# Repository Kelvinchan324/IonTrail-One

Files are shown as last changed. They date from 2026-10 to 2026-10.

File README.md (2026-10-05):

## EVT-A build and teaching manual (5 October 2026)

The runnable draft is a **USB-powered ESP32-C3 counter with a guarded SEN0463,
SHT40 and SSD1306 display**. Its 170 x 100 mm bench fixture is a development step;
the pocket battery product below remains a future design.

[Engineering manual](docs/engineering.md) · [BOM](hardware/BOM.md) ·
[Wiring schematic](hardware/schematic.svg) · [Placement drawing](mechanical/placement.svg) ·
[STEP draft](mechanical/layout-draft.step)

1. Confirm the exact C3 board, OLED pin order and 3.3 V signal levels against the
   engineering manual. Keep the detector guard closed. Do the first test with
   the detector disconnected and injected low-voltage pulses only.
2. Install PlatformIO, then run `pio run`, `pio run --target upload`, and
   `pio device monitor` at 115200 baud.
3. The screen starts at WAIT and reports CPM after ten seconds. A missing screen
   or environmental sensor should not prevent serial counting.
4. Supply 10 Hz pulses from a separate 3.3 V fixture through 1k into GPIO3.
   Collect at least three full windows and run
   `python tools/check_log.py capture.csv --hz 10`. Expect about 600 CPM.
5. Power off, remove the fixture, then connect the detector's low-voltage output.
   Record natural background counts. Hold the count-reset button for two seconds
   to clear totals; the next full measurement again takes ten seconds.
6. Complete the five lessons in the engineering manual before changing hardware.

The software emits CSV count/environment readings. It does not measure calibrated
dose, certify a safe environment or prove sensor health when counts are zero.
The CAD is a guarded-module packaging draft. Battery, custom HV board and final
pocket enclosure work are not complete.

New review drafts: [secondary bench cover STEP/STL and fit lesson](mechanical/README.md)
and [low-voltage power-budget worksheet](docs/power-review.md). Reproduce the
planning arithmetic with `python tools/check_power_budget.py`. Current allowances,
guard dimensions, retention and temperature remain unmeasured; passing the script
is not hardware approval.

The [STEP-derived enclosure review](mechanical/enclosure-visual-review.png) now
labels component positions and shows the lid raised for inspection only. The
detector guard size is still assumed, modules are not positively retained, and
the reset button cannot be used through the closed draft lid. These are open
design requirements; the illustration is not a fabrication or electrical release.

### Verification and troubleshooting

- Run `python -m pytest tests`; production counting-library host tests are
  documented in [tests/README.md](tests/README.md).
- Log validation checks raw window counts, elapsed time, total-count continuity
  and frequency agreement, not just the displayed CPM.
- WAIT: no full post-start/reset window yet. FAULT or `counts_valid=0`: counter
  overflow; stop the test, investigate, reset and record a new capture.
- `sensor_ok=0`: environmental data unavailable; it says nothing about GM health.
- Missing climate sensor at boot: initialization is retried once per completed
  count window. Failed or invalid reads publish `nan,nan,0`; the display stops
  showing a climate sample after 15 seconds without a valid update. Recovery
  requires a successful new read, not merely an I2C address acknowledgement.
- INIT FAIL: counter initialization failed; no count rows are emitted. A blinking
  status LED indicates loop activity only, not sensor or counter health.
- The SDK rejects out-of-range GPIO numbers and interrupt modes other than
  FALLING/RISING before touching the current acquisition. A successful `begin`
  still does not verify interrupt attachment or detector health. See the
  [counter-configuration lesson](docs/counter-configuration.md).
- OLED missing or initialization failed at boot: serial counting can continue,
  with a display connection probe/retry every two seconds. Detected loss suspends
  drawing; recovery reinitializes the display without restarting the shared bus.
  `# oled` log comments report transitions, not proof of working pixels. See the
  [display-recovery lesson](docs/display-recovery.md). Power off before checking
  wiring; do not hot-plug the detector or use this as permission to live-rewire.
- Zero counts cannot distinguish quiet conditions from a broken detector path.
- Record actual results in the [bench worksheet](docs/bench-record.md).

See the [environmental-data validity lesson](docs/climate-validity.md). The log
checker now checks climate fields when present; its pass result still certifies
neither sensor accuracy nor radiation dose.

The [application-loop lesson](docs/application-testing.md) now exercises the
production setup/loop and counter using host-only sensor/display doubles.
It covers missing/failed climate reads, delayed I/O, reset timing and counter
startup failure. This is simulated behavior coverage, not a physical bus test or
OLED pixel/layout validation; the lesson includes a separate pending bench record.

<p align="center">
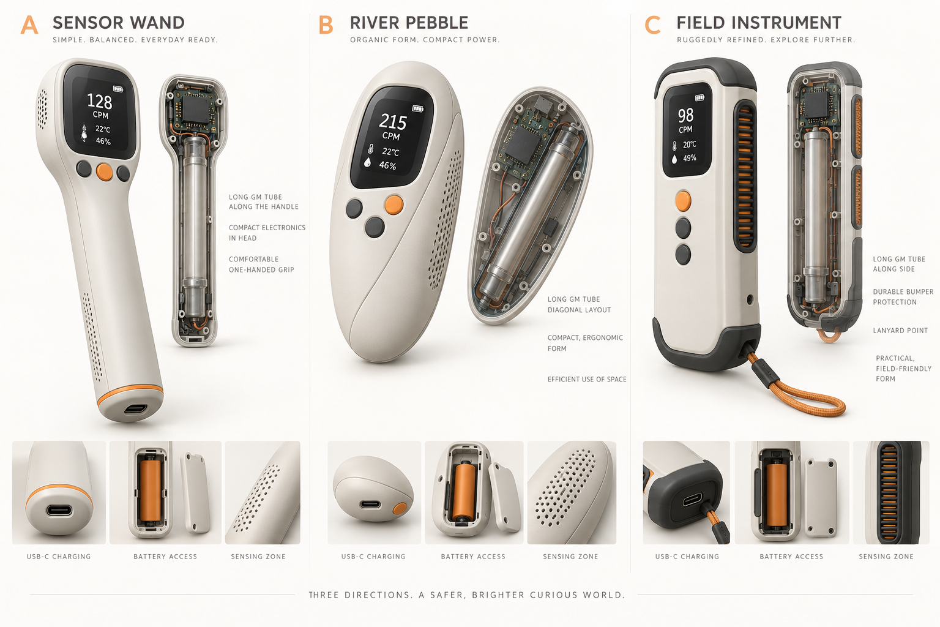
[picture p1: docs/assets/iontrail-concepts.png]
IonTrail One enclosure study
  
</p>

<p align="center">
  <strong>IonTrail One</strong><br>
  A pocketable environmental radiation counter designed to be explored, extended, and made your own.
</p>

<p align="center">
  <a href="docs/index.html"><strong>Product-page source</strong></a> ·
  <a href="docs/quickstart.md">SDK quick start</a> ·
  <a href="docs/hardware.md">Hardware architecture</a> ·
  <a href="docs/customization.md">Customization guide</a>
</p>

<p align="center">
  
  
  
</p>

---

## See the invisible environment

IonTrail One is a planned consumer environmental instrument built around a Geiger–Müller tube, an ESP32-C3, and temperature/humidity sensing. Its river-pebble enclosure uses a smoked transparent back to reveal the tube and custom PCB, while a structural loop lets it travel on a bag or lanyard.

The product is designed for home science, STEM learning, makers, collectors, and people curious about the world around them. CPM/CPS is the primary radiation measurement; environmental readings provide context for experiments and logged observations.

> **Development status:** concept and EVT planning. Dimensions, battery life, radiation response, dose conversion, ingress protection, and accuracy are not final specifications until verified on production-representative hardware.

## Product principles

| Principle | What it means |
| --- | --- |
| Understandable | The main screen explains the current count rate without presenting an unverified “safe/unsafe” judgement. |
| Customizable | The public SDK exposes count events, CPM, environmental readings, alarms, logging, and display hooks. |
| Repairable | A screwed enclosure, replaceable subassemblies, test points, and versioned hardware documentation are preferred. |
| Honest | Dose-rate estimates remain optional and require tube-specific calibration data supplied by the user or manufacturer. |
| Safe by design | The high-voltage section is physically guarded, current-limited, and inaccessible despite the transparent back. |

## Planned hardware

```mermaid
flowchart LR
    USB[USB-C 5 V] --> CHG[Protected charger<br/>and power path]
    CELL[Protected 1-cell LiPo<br/>with NTC] --> CHG
    CHG --> REG[3.3 V regulation]
    REG --> MCU[ESP32-C3]
    REG --> DISP[OLED display]
    REG --> ENV[SHT40 temperature/RH]
    REG --> HV[Regulated GM high voltage]
    HV --> TUBE[GM tube]
    TUBE --> PULSE[Pulse conditioning<br/>and input protection]
    PULSE --> MCU
    MCU --> FEEDBACK[Buzzer + pulse LED]
    MCU --> BLE[BLE customization API]
```

The ESP32-C3 SuperMini is used for fast EVT prototypes. A sellable revision should use a certified ESP32-C3 module on a custom PCB with traceable power components, protected battery charging, controlled high voltage, and production test points.

Read the full [hardware architecture](docs/hardware.md) and [prototype BOM](docs/bom.md).

## SDK overview

The SDK is organized as a small Arduino/PlatformIO library. Applications can subscribe to count-rate data, change display behavior, implement their own alarms, add BLE services, or connect additional I2C sensors without rewriting the pulse-counting core.

```cpp
#include <IonTrail.h>

IonTrailDevice ionTrail;
bool counterReady = false;

void setup() {
  Serial.begin(115200);
  IonTrailConfig config;
  config.gmPulsePin = 3;
  config.sampleWindowMs = 10000;
  config.deadTimeMicros = 0; // Enable only with characterized tube data.
  counterReady = ionTrail.begin(config);
  if (!counterReady) Serial.println("# counter INIT FAIL; no measurements");
}

void loop() {
  if (!counterReady) return;
  ionTrail.update();

  if (ionTrail.hasFreshReading()) {
    Serial.printf("CPM: %.1f  Total: %lu\n",
                  ionTrail.cpm(),
                  static_cast<unsigned long>(ionTrail.totalCounts()));
  }
}
```

### What customers can customize

- Screen layouts, icons, units, languages, and themes
- Count-click sound, LED behavior, and alarm thresholds
- BLE characteristics and companion applications
- CSV/JSON logging and cloud integrations
- Environmental sensors on the shared I2C expansion bus
- Experiment modes and classroom activities
- Tube-specific calibration profiles
- Power-saving and sampling strategies

The initial library deliberately does **not** make a universal CPM-to-µSv/h conversion. See [calibration and claims](docs/safety.md).

## Start developing

1. Install [Visual Studio Code](https://code.visualstudio.com/) and [PlatformIO](https://platformio.org/).
2. Clone this repository.
3. Connect an ESP32-C3 SuperMini by USB.
4. Review and confirm the pins in `include/iontrail_board.h` against your exact board revision.
5. Build and upload the default environment:

```bash
pio run
pio run --target upload
pio device monitor
```

See the [quick-start guide](docs/quickstart.md) before connecting any GM high-voltage hardware.

## Repository map

```text
IonTrail-One/
├── include/                 Board-level pin configuration
├── lib/IonTrail/            Reusable SDK library
├── src/                     Reference firmware application
├── examples/                Customer customization examples
├── docs/                    Product, hardware and SDK documentation
├── platformio.ini           Reproducible ESP32-C3 build
├── CONTRIBUTING.md          Contribution workflow
└── LICENSE                  MIT SDK licence
```

The static product site is ready in `docs/`. To publish it at `kelvinchan324.github.io/IonTrail-One`, enable **Settings → Pages → Build and deployment → GitHub Actions** once; the included workflow handles later deployments.

## Safety boundary

IonTrail One is an educational and environmental-monitoring project. It is not a certified personal dosimeter, contamination survey meter, medical device, or proof that an environment is safe. A GM circuit can contain several hundred volts even when powered by a small battery. Use a current-limited design, discharge path, insulating guard, and appropriate test equipment. Never connect a tube or high-voltage node directly to an ESP32 pin.

Read [Safety, calibration and product claims](docs/safety.md) before modifying detector hardware or publishing measurements.

## Contributing

Issues, documentation improvements, display themes, sensor integrations, translations, and tested hardware profiles are welcome. Keep safety-critical changes explicit and include test evidence where practical. See [CONTRIBUTING.md](CONTRIBUTING.md).

## Licence

The SDK and repository content are available under the [MIT License](LICENSE). Product names and logos are not granted for use as trademarks. Third-party libraries and hardware modules retain their own licences and terms.

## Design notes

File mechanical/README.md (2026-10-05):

# Secondary bench cover — editable draft, not an electrical guard

Retain the **complete factory SEN0463 enclosure**. This outer cover does not
replace it or certify protection against electric shock, dust, moisture, fire,
drops or access through openings. No pocket or wearable use is approved.

Files:

- [Parameters](enclosure-parameters.json) and [computed checks](enclosure-checks.json).
- [Tray STEP](bench-tray-draft.step) / [STL](bench-tray-draft.stl).
- [Lid STEP](bench-lid-draft.step) / [STL](bench-lid-draft.stl).
- [Assembly with original fixture and component envelopes](enclosure-layout.step).

Generate using `python tools/build_enclosure.py` with CadQuery 2.8.0 after
`python tools/build_engineering.py --cad`. The part generator verifies connected
positive solids, no reference-envelope or fixture-plate intrusion and STEP
roundtrips. It does not model screws, cables, plug insertion or material strength.

## Geometry and fastening

Original fixture datum is unchanged: plate bottom Z=0, top Z=4 mm. Tray bottom
extends to Z=-9; the underside datum is now -9, not the old fixture datum.
Through-bolt heads/nuts may project below it: insulating feet or clearance
supports are still required and not modeled. Do not rest the assembly on fasteners.
The lid footprint is 202 x 107 mm and overall height is 53.5 mm. Four 6 mm-high
support bosses line up with the existing plate holes at X=±78, Y=±43 mm.
Do not confuse these holes with detector or module mounting patterns.

Lid bolts use external ears at X=±95, Y=±43 mm, keeping hardware outside the
detector bay. Holes are 3.4 mm; M3x16 through-bolts are candidates only. Check
washer/nut/tool access and thread engagement on the actual manufactured parts.
The lid is a flat transparent-material candidate, not a proven clear 3D print.
There is no gasket or light-seal performance claim.

The left-wall USB opening is provisional: verify the board connector orientation,
plug size and cable bend before fabrication. Three lid vents are above the
environment sensor, not over the detector. Their existence is not a touch-probe
assessment. The reset button cannot be operated with this lid closed; its
extension actuator remains unresolved. Power must be removed before lid removal.

## Guard retention is deliberately not guessed

The [vendor specification](https://wiki.dfrobot.com/sen0463/) lists a 107 x 42 mm
board. The retained 115 x 48 x 28 mm envelope is an **assumed guard allowance**,
not a measured outer case. No new holes, clamp pressure or fastener force on the
factory guard/tube is specified. Modules are not secured merely by enclosing them.
Do not power, transport or shake this draft until proper retention is reviewed.

## Measurement and CAD lesson

1. With all supplies removed, measure the intact exterior without disassembly.
2. Record guard dimensions, allowed factory mounting points, low-voltage cable
   exit and clearance. Photograph external evidence; never expose the HV section.
3. Update the envelope and regenerate both layout and cover. Investigate any
   intrusion error rather than suppressing it.
4. Design a removable adapter using verified factory mounting features. Do not
   assume adhesive or pressure against a tube is acceptable retention.
5. Prototype fit with inert dummy blocks first. Record wire pinch, plug access,
   lid bow and fastener stack before considering electronics.

| Required measurement | Evidence |
| --- | --- |
| Factory guard W/D/H and allowed retention interfaces | pending |
| Board/connector positions and cable clearance | pending |
| Plate bolt stack and lid-ear nut/tool clearance | pending |
| Insulating feet / underside fastener clearance and stability | pending |
| Transparent lid readability and button solution | pending |
| Material, thickness tolerance, deflection and thermal suitability | pending |
| Positive retention, strain relief and accessible-opening review | pending |

Release remains blocked on these measurements and the
[power/thermal review](../docs/power-review.md). No physical tests have run.

## Visual handoff and source freshness

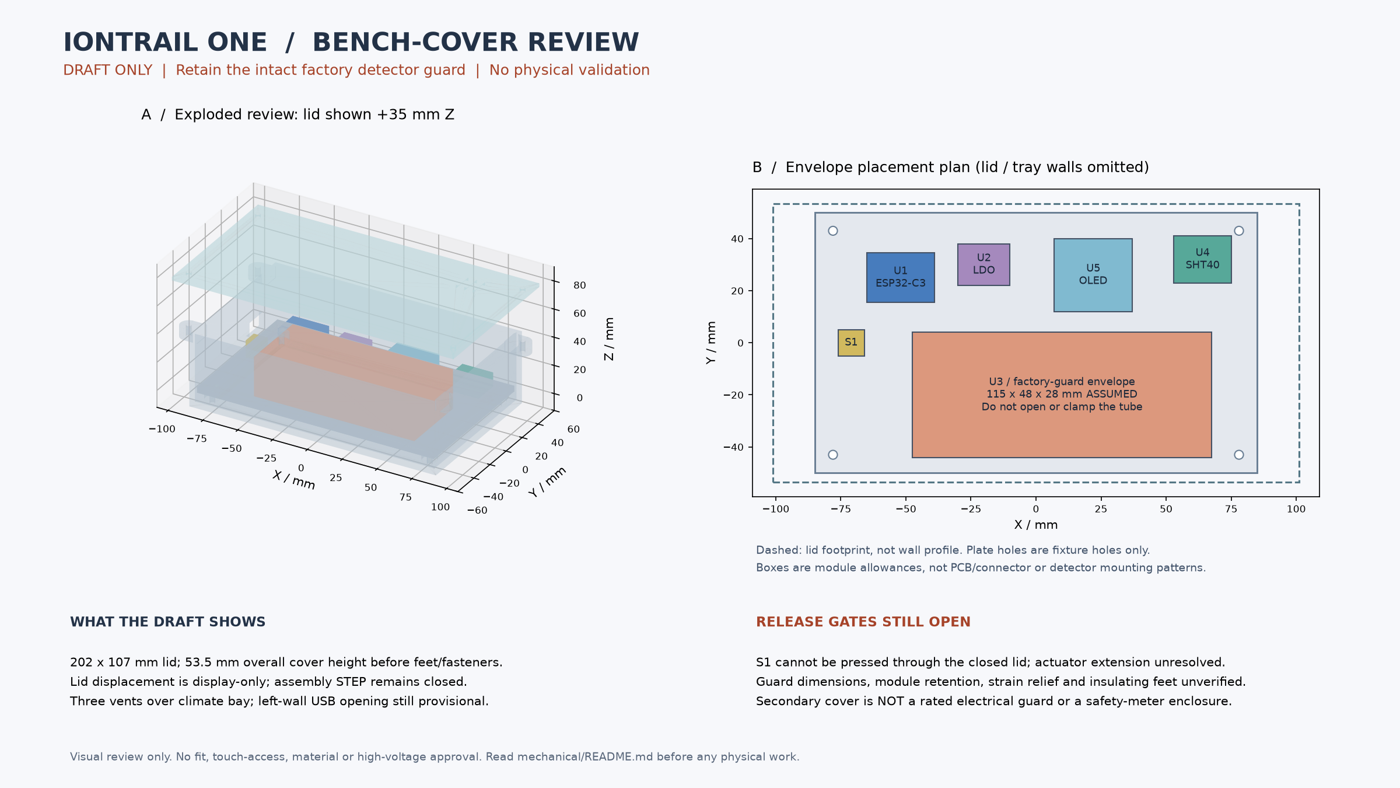
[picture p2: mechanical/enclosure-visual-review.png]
STEP-derived exploded cover and component placement


The left view uses the saved tray, lid and fixture STEP solids with the six
component-envelope boxes. The lid is displaced **35 mm upward for illustration
only**; the original assembly file remains closed. Translucency is an inspection
aid, not a verified material property. The right view omits lid and tray walls to
show component positions: dashed outline is the lid extent, not a wall profile.
Fixture holes are not module mounting patterns. No power wiring is depicted.

The render was visually checked, including correction of an overlapping axis
caption. The plan makes the current division between the guarded detector and
low-voltage electronics clear. It does not establish an electrical isolation
distance or prevent a loose module crossing that division. S1's inaccessible
closed-lid position, missing module retention and underside feet remain release
blockers, not details to overlook during assembly.

Reproduce with CadQuery 2.8.0 and Matplotlib 3.11.2:

```sh
python tools/render_enclosure_review.py
python -m pytest tests/test_visual_review.py
```

The [ledger](enclosure-visual-review.json) records input/image hashes, versions
and nine matched bodies. Before drawing, the renderer checks one-to-one body
volumes (within 1e-4 mm3) and bounds (within 1e-4 mm) against enclosure-layout.step,
plus the lid's bottom datum against parameters. This is not a topological
identity, fit, intrusion, retention or electrical-safety proof. STEP geometry is
not rewritten. Text hashes normalize CRLF to LF; STEP/PNG preserve native bytes.
The regular Python CI suite flags stale source/image hashes without installing
CAD libraries. Regenerate **and visually inspect** after changing source files.

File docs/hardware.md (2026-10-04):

# Hardware architecture

IonTrail One combines a long GM tube with a compact ESP32-C3 platform inside a river-pebble enclosure. The architecture below separates fast prototyping decisions from the requirements of a sellable product.

## EVT prototype

| Subsystem | Prototype choice | Purpose |
| --- | --- | --- |
| Controller | ESP32-C3 SuperMini | Firmware, USB development, BLE and logging |
| Detector | J305βγ or SBM-20 candidate | Compare sensitivity, length, supply needs and sourcing |
| High voltage | Current-limited 400 V GM module with pulse output | Rapid detector evaluation |
| Environment | SHT40 breakout | Temperature and relative humidity |
| Display | 0.96-inch SSD1306 OLED | Simple low-power interface |
| Battery | Protected 1-cell LiPo with NTC | Portable power |
| Charging | USB-C charger module for bench prototypes | Charging during EVT only |

## Product revision

A product PCB should replace the module stack. Use a traceable, certified ESP32-C3 module; USB-C input protection; a charger with power-path behavior; protected cell and temperature monitoring; regulated logic supply; controlled and current-limited GM high voltage; protected pulse conditioning; manufacturing test points; and a hardware revision identifier.

The transparent back should expose only safe surfaces. Cover the complete high-voltage zone with an opaque, mechanically retained insulating guard. The visual PCB can still reveal the tube, low-voltage components, antenna keep-out, and deliberate routing.

## Mechanical arrangement

- Place the tube along the widest internal diagonal.
- Support the tube near both ends with compliant silicone saddles; do not clamp the glass or metal wall rigidly.
- Make the attachment loop part of the internal chassis, not a cosmetic shell feature.
- Isolate impact loads from the tube, solder joints, battery, and transparent window.
- Vent the humidity sensor through a protected labyrinth away from warm components.
- Use screws for serviceability and reserve adhesives for validated seals or strain relief.

## Provisional pin map

The current firmware map lives in `include/iontrail_board.h`. Verify it against the actual development board before assembly. Generic “ESP32-C3 SuperMini” boards can vary by seller and revision.

## Validation gates before sale

1. GM tube operating voltage, plateau and pulse-interface characterization.
2. Instrument response testing against appropriate reference sources and facilities.
3. Battery, charging, thermal, short-circuit and fault testing.
4. USB, ESD, EMC/radio, drop, vibration and attachment-loop testing.
5. Enclosure material, flammability, accessibility and high-voltage protection review.
6. Applicable market compliance, labeling, transport and recycling requirements.

This document is an engineering plan, not a certification claim.

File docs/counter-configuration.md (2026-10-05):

# Counter configuration and startup lesson

Status: source-reviewed and host-tested draft, 5 October 2026. No hardware test.

## Contract

The supported build uses ESP32-C3 GPIO3 with `FALLING`, one selected edge per
pulse, a 10,000 ms window and no software dead-time rejection. `begin` rejects:

- Negative GPIO values, numbers outside the target SoC domain, or an invalid
  GPIO according to the target mask. Validate the original integer before any
  narrowing conversion or mask shift. On C3 the numeric domain is 0 through 21.
- Any mode except `FALLING` or `RISING`. `CHANGE` counts both edges of a normal
  pulse; a level-triggered mode can repeatedly interrupt while the level persists.
- A zero window or window/dead-time interval at least 2^31; another library
  instance already owning the counter interrupt.

Invalid reconfiguration returns false without detaching, resetting totals,
discarding pending pulses or changing the window start. Valid reconfiguration
does reset acquisition. Call these methods from one foreground task only.

Numeric pin validity is **not board suitability**: flash, USB, boot straps,
reserved functions and board wiring still require review. GPIO3 is the only
reference detector input; this change does not authorize rewiring.

`begin == true` means accepted configuration and an attempted Arduino attachment,
not an acknowledged driver initialization. The pinned Arduino API returns void;
its internal service installation can fail and its GPIO calls are not checked by
this library. External code could replace the same interrupt. Likewise,
`counts_valid=1` means count arithmetic has not overflowed, not that the detector
or signal path is healthy. Zero counts cannot establish a safe environment.

## Reproduce the lesson without hardware

1. Run the counter and basic-example commands in [tests/README.md](../tests/README.md).
2. Inspect the rejected inputs: -1, 22, 255, 256, 259 and integer extremes.
   Explain why 259 becomes 3 when narrowed to eight bits.
3. Explain why counting both edges can double a pulse count. The implementation
   rejects that mode; do not try level-triggered counting on the detector.
4. Follow the active-measurement test: one completed window, one pending pulse,
   rejected reconfiguration, then another completed window. Neither the pending
   count nor original epoch may disappear.
5. Read the starter sketch's explicit failed-initialization branch. Test doubles
   inject competing library ownership; no real allocation failure is simulated.

## Pending physical acceptance

Use the existing [bench record](bench-record.md), with detector disconnected,
guard closed, and the approved 3.3 V low-voltage pulse fixture only. Check the
actual board GPIO mapping, input waveform levels and pulse widths, then record
three full windows at known pulse frequencies and validate the serial capture.
Repeat while display/climate I/O runs. Record loss or extra counts, not just CPM.
Do not call a successful build or synthetic test a measured throughput result.
Never probe an HV node or remove the vendor guard for this lesson.

## Primary source basis

- [Arduino-ESP32 2.0.17 GPIO implementation](https://github.com/espressif/arduino-esp32/blob/2.0.17/cores/esp32/esp32-hal-gpio.c)
  and [GPIO declarations](https://github.com/espressif/arduino-esp32/blob/2.0.17/cores/esp32/esp32-hal-gpio.h):
  eight-bit pin argument, mode constants and void attachment behavior.
- [Arduino pin mapping](https://github.com/espressif/arduino-esp32/blob/2.0.17/cores/esp32/Arduino.h)
  and [ESP-IDF 4.4.7 C3 capabilities](https://github.com/espressif/esp-idf/blob/v4.4.7/components/soc/esp32c3/include/soc/soc_caps.h):
  original integer must be range-checked before conversion/mask use.

Reviewed local PlatformIO framework 3.20017.241212+sha.dcc1105b. GPIO C-source
SHA-256: `9e9c47f299ce5a57ac6bd41b57eb0481df75eb3de17815f0aad4f5faa040f102`.
The native shim models the C3 numeric domain and attachment signature, not actual
ISR service allocation, electrical edge detection, concurrency or throughput.

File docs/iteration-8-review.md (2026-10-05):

# Iteration 8 — reject invalid counter configuration before GPIO side effects

5 October 2026. Software draft only; no connected detector or hardware test.

The reusable counter previously rejected negative GPIO numbers but accepted
oversized positive integers and arbitrary interrupt modes. The pinned Arduino
API narrows its pin argument to eight bits: 259 could target GPIO3. A both-edge
mode could count twice per pulse; level modes are unsuitable for this counter.

`begin` now checks the original integer against the target GPIO range/mask and
accepts only FALLING or RISING. Validation precedes every pin/interrupt operation
and preserves an active acquisition when rejecting a new configuration. The
GPIO3/FALLING reference build and CSV schema are unchanged. The starter sketch
and README example now check initialization and suppress readings on failure.

Counter tests cover invalid integer boundaries and modes before/after successful
startup, zero GPIO side effects on rejection, pending-count/last-reading/window
preservation and accepted edge modes. A fourth native executable includes the
actual basic-counter sketch and tests success and competing-owner failure. CI
now runs it. The host shim models the pinned eight-bit attachment signature and
C3 GPIO domain, not a real interrupt subsystem.

Verification: all four native suites pass with C++17 and strict warnings;
54 Python tests and the power-planning arithmetic pass. ESP32-C3 firmware build
passes: RAM 14,648 bytes, flash 282,342 bytes. Remote engineering CI is pending
at commit time. No website deployed, hardware flashed, or CAD/BOM/pins changed.

The [configuration lesson](counter-configuration.md) records primary sources,
reproduction steps and pending low-voltage physical tests. A successful `begin`
still cannot acknowledge Arduino's void attachment call or prove detector
health. Board pin reservations, interrupt allocation failure, real pulse
throughput, electrical integrity, calibration and enclosure retention remain
unverified. The passing software tests do not make this a finished product.

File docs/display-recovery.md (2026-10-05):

# OLED availability and recovery lesson

5 October 2026. Tested with scripted host doubles and an embedded build, not a
real display or I2C fault-injection fixture. Keep the detector guard intact.

## What the firmware does

At boot, the firmware probes the configured display address and initializes the
SSD1306 only if the address acknowledges. It probes again at most once every
2,000 ms of the running loop; delayed loops make one attempt, not a catch-up
burst. A missing acknowledgement clears display availability and suppresses
future drawing until recovery. Failed initialization is retried on that same
schedule. When the display is already available, a successful probe does not
reinitialize it or clear its buffer.

Recovery uses the existing display object, with hardware reset and shared-Wire
initialization disabled. It checks acknowledgement again after initialization.
New contents appear on the next scheduled 500-ms UI refresh, not necessarily in
the same loop. A lost acknowledgement during initialization is not reported as
recovery. Transition comments start with `# oled`; CSV columns are unchanged.

| Observation | Interpretation |
| --- | --- |
| `# oled unavailable` | A scheduled address probe failed; drawing is suspended |
| `# oled available; address ACK, pixels unverified` | Probe/init/post-probe passed, but visible output is unconfirmed |
| Count rows continue | The foreground counter is producing records; not proof of detector or display health |
| Frozen image or no new count rows | Investigate the system; never interpret old pixels as a current measurement |

Count-window timestamps remain the counter snapshot endpoint, before climate or
display I/O. UI time is refreshed after synchronous display recovery. A retry can
delay the loop; the two-second schedule is **not** a maximum fault-detection or
stop-latency guarantee. Probe-only checks can miss short outages, silent display
resets or failed pixels while the controller still acknowledges.

## Driver basis and limits

Reviewed pinned [Adafruit SSD1306 2.5.17 source](https://github.com/adafruit/Adafruit_SSD1306/blob/2.5.17/Adafruit_SSD1306.cpp):
`begin()` allocates a framebuffer only if one is not already present; retries on
the same object reuse it. The false `periphBegin` argument leaves the shared bus
setup to the application. `display()` returns no transfer result, and internal
I2C transmission results are not propagated as a successful-frame acknowledgement.
Thus `displayReady` means software initialization plus sampled address presence,
not verified visible content. Address acknowledgement also does not identify an
SSD1306 uniquely. Confirm the actual module and pin order before any wiring.

Installed source SHA-256:
`ddbd788bfaf97dd3b5ba5ee67eb62ab51652cbe86e34c2e7d24d5e074bb34bdd`.
This review does not prove behavior of every clone, power transient or stuck bus.
The shared Wire timeout is configured to 50 ms, but multiple synchronous driver
transfers, driver faults and MCU failure are not an independent watchdog.

## No-hardware classroom exercise

1. Run the production application-loop test from [tests/README.md](../tests/README.md).
2. Explain why startup without an OLED can still produce serial count windows.
   Distinguish missing address, failed initialization and failed screen pixels.
3. Trace the test's absence/reappearance sequence. A 31,999-ms UI refresh followed
   by recovery at 32,000 ms does not immediately draw; the next eligible UI update
   is at 32,499 ms. Do not treat a scheduling assertion as measured wall-clock time.
4. Inspect the delayed-recovery test: count row endpoint remains 10,000 ms while
   the simulated UI clock advances to 10,600 ms. Explain why changing the count
   timestamp to the later time would misrepresent the count interval.
5. Explain what remains invisible to an ACK probe: frozen pixels, wrong display
   identity, silent reset, data corruption and a failed Geiger detector.

## Physical validation — all pending

Record exact OLED/controller marking, board revision, supply/current, actual
bus levels, source commit and test equipment. Use a separate reviewed low-voltage
test fixture with detector disconnected. De-energize before modifying wiring;
do not hot-plug the detector or expose its high-voltage section.

Measure startup/recovery latency, count-window continuity, bus timeout behavior,
visible text/layout, retry memory/stack use and response to controlled power loss.
Check wrong-address and missing-module cases. A fault test must not depend on an
unreviewed live cable disconnection. Keep failed trials and actual traces; never
copy host-test outputs into measured-result fields. This is not a safety meter.

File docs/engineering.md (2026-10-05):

# IonTrail One EVT-A engineering draft

The current build is a USB-powered bench instrument using an intact DFRobot
SEN0463 detector inside its guard. This is larger than the original pocket
concept. It deliberately establishes counts, display, environmental context
and logging before a custom battery or high-voltage board is designed.

## Build package

- [Pin/net schematic](../hardware/schematic.svg) and [BOM](../hardware/BOM.md).
- [Editable revision](../hardware/rev-a.json).
- [Placement drawing](../mechanical/placement.svg), [STEP assembly](../mechanical/layout-draft.step).
- [Fixture plate STEP](../mechanical/fixture-plate.step) / [STL](../mechanical/fixture-plate.stl).
- [Secondary bench cover and retention measurement lesson](../mechanical/README.md).
- [Reproducible power allocation and thermal review](power-review.md).
- Regenerate with `python tools/build_engineering.py --cad` (CadQuery 2.8.0).
  Without `--cad`, only Python standard library is needed.

These are module-level connection schematics and envelope CAD. No custom
high-voltage PCB, battery charger, enclosure ingress rating or calibrated dose
conversion is released. Unused pins in the original concept remain unconnected.

## Electrical design

USB powers the selected ESP32-C3 SuperMini and AP2112K-3.3 auxiliary regulator.
Confirm the exact SuperMini board schematic; the name alone does not identify a
single vendor revision. The AP2112 pin list is for SOT25, not other packages.
The manufacturer's [DS39724 revision 2-2](https://www.diodes.com/datasheet/download/AP2112.pdf)
pin diagram confirms VIN=1, GND=2, EN=3, NC=4 and VOUT=5 for SOT25.
The diagram does not establish the terminal order of an assembled breakout.
Use a properly assembled breakout and local input/output ceramic capacitors.
The auxiliary 3.3 V rail supplies the detector, screen and SHT40.
It must NOT be tied to the MCU's regulator output.

All signals are referenced to common GND. SEN0463 D connects through 1k to
GPIO3; its supply is 3.3 V in this build. Use only the low-voltage signal connector.
GPIO4/5 are SDA/SCL at 100 kHz, with 3.3 V pull-ups supplied by the breakouts.
Measure equivalent pull-up resistance before adding more. Sensor address is
0x44; display is a 3.3 V compatible SSD1306 128x64 at 0x3C. Verify every purchased
module's connector order; silkscreen order is not standardized.

GPIO0 has a normally-open button to ground; hold two seconds to reset totals.
GPIO7 drives a green LED through 1k. It indicates firmware activity, not detector
health. GPIO2 is unused because the previous battery ADC assignment conflicts
with a boot-strapping pin. There is no battery in EVT-A.

Sources accessed 5 October 2026:
[DFRobot SEN0463](https://wiki.dfrobot.com/sen0463/),
[Diodes AP2112](https://www.diodes.com/part/view/AP2112/),
[Adafruit SHT40](https://learn.adafruit.com/adafruit-sht40-temperature-humidity-sensor/pinouts).
The detector board is listed as 107 x 42 mm; the CAD allows a larger guard volume.
Check the supplied guard dimensions. Keep the module intact: its internal
operating voltage is approximately 400 V despite its low-voltage input.

Before powering, measure rails without sensors and check polarity. Begin with
a current-limited USB source. Budget auxiliary current initially at <=150 mA
pending measurements; AP2112 dissipation is (5-3.3)*I, e.g. 0.255 W at 150 mA.
The module regulator rating alone does not prove acceptable breakout temperature.
USB connector, trace capacity and total board current still need verification.
The power-budget script now checks explicit unmeasured allowances and scenarios;
see its worksheet before interpreting the 150 mA ceiling as an achieved result.

## Packaging

The 170 x 100 x 4 mm fixture plate is a bench layout, not the pocket enclosure.
Detector occupies the long lower bay. MCU/USB is at the opposite edge;
SHT40 is at the outer upper corner, separated from regulator heat.
OLED faces outward and the count-reset button remains reachable.
No vent or screw may defeat the original detector guard.
All positions in [placements.json](../mechanical/placements.json) are editable
assumptions; module mounting holes are not invented. Retain factory guard mounts
and develop the final retention features from measurements.

## Firmware and user behaviour

Screen reports WAIT until a full 10-second interval completes. The reported CPM
is pulses * 60000 / measured interval in milliseconds. No universal dose factor,
background subtraction, alarm threshold or safe/unsafe label is applied.
SHT40 failure displays unavailable, while counting and serial output continue.
A missing display is tolerated; the serial output remains the primary diagnostic.
The OLED address is rechecked every two seconds; a detected loss suspends display
updates, and a returned address permits bounded reinitialization. Read the
[display-recovery lesson](display-recovery.md): an address ACK does not verify
pixels or counter/detector health, and shared-bus electrical faults can still
affect synchronous I/O. No live rewiring or detector hot-plug is authorized.
Reconnect missing I2C modules with power off and restart to re-detect them.

USB serial runs at 115200 and emits a CSV header, one row per complete window,
and '#' diagnostic lines. Capture it to a log using a serial terminal.
The current columns are `uptime_ms,window_ms,window_counts,cpm,total_counts,
temperature_c,humidity_percent,sensor_ok,counts_valid` (one header line).
Counts saturate instead of wrapping; overflow latches `counts_valid=0`, emits
nonfinite CPM and displays FAULT. Stop the capture, investigate and reset before
starting another test. This detects integer overflow, not detector saturation,
unobserved pulses or a disconnected cable.

The optional dead-time filter accepts the first pulse, then rejects intervals
shorter than the configured value; it is disabled in the reference application.
It does not correct a GM tube's physical dead time. Foreground SDK calls belong
to one loop/task. `end()` releases the interrupt so another instance can start.
A ten-second window has coarse resolution: one count contributes 6 CPM.
For independent Poisson events, the approximate standard deviation scales as
sqrt(N); tiny samples are noisy. This describes counting statistics, not detector
energy response or calibrated accuracy. Zero counts can mean either quiet
conditions or broken hardware.

## Teaching and test plan

1. **Pulse counting (45 min):** leave detector disconnected. Use a 3.3 V signal
   generator, or the separate-board [pulse fixture](../tools/pulse_fixture/pulse_fixture.ino).
   Its GPIO4 drives low pulses through 1k into GPIO3; join grounds. Never combine
   the fixture output and detector output. Ten hertz should yield about 600 CPM.
2. **Reproducibility (30 min):** capture >=3 windows, then run
   `python tools/check_log.py capture.csv --hz 10`. The first captured window is
   excluded only from the frequency comparison; its arithmetic must still be valid.
   Later rows must have contiguous uptime, matching count increments, valid flags
   and CPM consistent with their raw counts. Missing rows, resets during a capture,
   and malformed data fail. Repeat at 1, 10 and 100 Hz with a characterized generator and record
   raw counts, exact period, rejected/missing pulses and measured signal level.
3. **Display/sensors (30 min):** disconnect one I2C module with power off.
   Restart; verify count logging survives. Compare temperature after warm-up
   with a reference placed outside the enclosure.
4. **Background measurement (60 min):** connect the guarded detector, collect
   background counts only, compare 10-second and longer aggregated windows.
   Do not acquire or handle radioactive sources for this lesson.
5. **Engineering review (30 min):** check reset, power cycle, CSV import,
   connector strain and regulator temperature. Attach measurements and firmware hash.

Completion gates: exact MCU/display revision, verified guard retention, injected
pulse fidelity, power/thermal measurements and calibrated-reference assessment.
Battery and pocket enclosure design follow those results.

Use the [blank bench record](bench-record.md) for measurements and
[software test guide](../tests/README.md) for reproducible host checks.

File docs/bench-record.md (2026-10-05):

# EVT-A bench record — copy before testing

Status: **blank template; no measurement below has been performed**.
Use low-voltage pulse injection first. Keep the detector disconnected during that
test. Do not probe, modify or open its guarded high-voltage section.

## Traceability

| Field | Record |
| --- | --- |
| Date / operator / reviewer | Not recorded |
| Firmware commit and environment | Not recorded |
| MCU vendor / board revision / photograph | Not recorded |
| Detector model / guard revision | Not recorded |
| Display model / address / connector order | Not recorded |
| SHT40 breakout revision | Not recorded |
| Regulator exact part / package / breakout | Not recorded |
| Power source / current limit | Not recorded |
| Instruments / calibration dates | Not recorded |
| Ambient temperature / enclosure configuration | Not recorded |

## Unpowered and electrical checks

| Check | Expected design condition | Measured result / evidence | Pass? |
| --- | --- | --- | --- |
| Harness continuity | Matches revision netlist; no reversed supply | Not tested | — |
| Auxiliary and MCU 3.3 V outputs | Not directly tied together | Not tested | — |
| Detector guard | Factory guard intact, retention undisturbed | Not tested | — |
| USB rail | Within exact board/regulator specifications | Not tested | — |
| Auxiliary rail | Within selected module specifications at load | Not tested | — |
| I2C pull-up equivalent | Verify parallel breakout pull-ups and rise time | Not tested | — |
| Pulse high / low / width | Compatible with MCU limits and selected edge | Not tested | — |
| Auxiliary current and regulator temperature | Record at boot and after 30 min; assess exact datasheet/board limits | Not tested | — |
| Power-off interaction | No unintended powering through signal pins | Not tested | — |

Do not accept a hot regulator merely because its headline current rating exceeds
the load. The assumed auxiliary budget is 150 mA pending thermal measurements.

## Injected-pulse acceptance

Use a characterized 3.3 V pulse generator through 1k into GPIO3, common ground,
detector output disconnected. The supplied separate-board fixture is nominal
10 Hz, not a calibrated frequency standard; measure its output.

| Reference frequency | Expected counts per nominal 10 s | Expected CPM | Recorded count / interval / CPM | Evidence |
| ---: | ---: | ---: | --- | --- |
| 1 Hz | 10 | 60 | Not tested | — |
| 10 Hz | 100 | 600 | Not tested | — |
| 100 Hz | 1000 | 6000 | Not tested | — |

Capture at least three complete CSV windows at each frequency without pressing
reset mid-capture. Run `python tools/check_log.py capture.csv --hz <measured-Hz>`.
The default ±12 CPM comparison is an initial bench tolerance, not a calibrated
accuracy claim. Choose and justify tolerance using source uncertainty, gating and
count quantization. Keep raw logs and checker output with this record.

## Failure behavior and teaching evidence

| Exercise | Expected behavior | Actual evidence |
| --- | --- | --- |
| Start/reset | WAIT until a full new interval; totals cleared | Not tested |
| Button held longer than 2 s | One reset per hold, next reset only after release | Not tested |
| No pulses | Zero-count windows; no healthy/safe claim | Not tested |
| Missing SHT40 at boot | sensor_ok=0 and nan climate fields; counting continues; init retried per completed window | Not tested |
| Transient climate communication failure | Invalid climate fields immediately on failed read; new successful read restores them | Not tested |
| Climate sample ages beyond 15 s without a new valid reading | Display shows Climate unavailable, not cached numbers | Not tested |
| Inconsistent climate CSV validity flag | Offline validator rejects capture | Not tested |
| Counter initialization failure | INIT FAIL when OLED available; no count data rows; LED is not a health indicator | Not tested |
| Missing OLED at boot | CSV continues | Not tested |
| Interrupted CSV / duplicated row | Offline validator rejects capture | Not tested |
| Detector reconnected with power off | Intact guard, correct low-voltage connector | Not tested |

Instructor sign-off requires explaining CPM versus calibrated dose, distinguishing
MCU overflow from physical pulse loss, and identifying which checks need real
instruments. Never acquire radioactive material for these exercises.

Final disposition: **NOT TESTED**. Attach failures and revised drawings; do not
erase failed results when repeating a test.

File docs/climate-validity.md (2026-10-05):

# Environmental data validity and recovery

Date: 5 October 2026. Software-tested draft; **no sensor, display or electrical
failure experiment has been performed**. Environmental availability is separate
from pulse counting. Neither `sensor_ok` nor `counts_valid` establishes detector
health, dose calibration or environmental safety.

## Firmware behavior

| Condition | CSV / display behavior | Recovery |
| --- | --- | --- |
| Climate module absent at boot | `nan,nan,0` climate fields; count windows continue | Try initialization once per completed count window |
| Initialized module read fails | Immediately invalidate cached climate data for the next row/display update | Retry ordinary measurement on the next completed window |
| Read reports success but values are nonfinite or RH is outside 0–100 | Treat the whole climate pair as unavailable | Require a new valid reading |
| No new valid climate sample for more than 15 seconds | Display says Climate unavailable | New valid sample restores display |
| Counter initialization fails | OLED says INIT FAIL if available; no count data rows | Inspect hardware/configuration and deliberately restart after correction |
| Display absent at boot | Serial CSV remains the output | OLED automatic reconnection is not implemented |

The current nominal count window is ten seconds. The 15-second climate display
age bound is a software policy allowing ordinary scheduling delay, not a sensor
specification or a safety limit. Validity expires strictly beyond that bound.
The CSV climate sample is taken when a count window completes; it is a point
sample, not a ten-second environmental average. `uptime_ms` continues to label
the count-window endpoint before climate I/O, so the two acquisitions are not
simultaneous. A reset postpones the next complete count window and can cause
the previous climate display value to expire.

After successful initialization the firmware keeps that driver instance and
retries `getEvent`, without repeated `begin` calls. Before first success, it
probes address 0x44 and attempts initialization at most once per completed count
window. A responding address is not enough: availability still requires a
successful measurement. No automatic bus power cycling is performed.

The pinned [Adafruit SHT4x 1.0.5 source](https://github.com/adafruit/Adafruit_SHT4X/blob/1.0.5/Adafruit_SHT4x.cpp)
checks I2C operations and CRC in its combined measurement method, clamps the
converted humidity to 0–100, and returns a success flag. IonTrail uses that
combined method, then applies its own finite-number and humidity-range checks.
This does not detect calibration drift, a plausible but wrong value, heat bias
from the enclosure, or all electrical faults. The heater remains disabled.

I2C calls are synchronous, with the existing 50 ms Wire timeout. An MCU freeze,
driver hang or electrically stuck bus is not an independently supervised fault.
If the foreground loop hangs, the display can freeze too. The status LED means
only foreground-loop activity; it is never a healthy/safe indicator.

## CSV contract

The existing header is unchanged. When climate columns are present, the checker
requires all three: `temperature_c`, `humidity_percent`, `sensor_ok`.

- `sensor_ok=1`: both values finite, humidity within 0–100.
- `sensor_ok=0`: both numeric fields must be `nan`, not zeros or cached readings.
- Missing climate columns as a complete group remain valid for legacy
  counter-only tests. Partial groups and duplicate CSV column names are rejected.

Temperature has no operating-limit acceptance test here; finite does not mean
accurate, calibrated or inside the exact hardware's rated environment. A passing
log check establishes arithmetic/schema consistency and comparison against the
requested injected frequency only. It cannot assess the sensor's true accuracy.

## Teaching exercise and physical evidence gate

1. Run the native climate test and `python -m pytest tests/test_check_log.py`.
   Contrast zero degrees/zero RH with unavailable `nan` values.
2. In a synthetic CSV copy, set `sensor_ok=1` while temperature is `nan`; confirm
   rejection. Set both climate fields to `nan` with `sensor_ok=0`; valid pulse
   data should still pass. Do not label the synthetic file as a measurement.
3. Predict the 15,000/15,001 ms validity boundary and clock-rollover result.
4. Before physical experiments, obtain a reviewed low-voltage fixture/test
   procedure with the detector disconnected. Configure missing modules only
   while power is off. Do not hot-plug the shared I2C harness or touch/open the
   detector's high-voltage guard to force faults.
5. Record actual startup absence, transient communication fault, recovery and
   delayed-sample display behavior in the [bench record](bench-record.md). Use an
   approved fixture or simulated driver for transient faults; do not short bus
   lines. Record count continuity separately from climate availability.

Required evidence remains blank: exact SHT40 breakout and pull-ups, bus rise time,
timeouts/recovery latency, OLED behavior, power-off signal interactions, reference
temperature/RH comparison and enclosure heat bias. The next physical build is
not approved merely because the host tests or firmware compile pass.

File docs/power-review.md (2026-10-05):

# Low-voltage power planning and test worksheet

No measured current, heat rise, USB compliance or battery runtime is claimed.
Use `python tools/check_power_budget.py` to reproduce the arithmetic from
[`hardware/power-budget.json`](../hardware/power-budget.json). A zero exit code
means the planning inequalities pass, NOT that hardware has passed.

## Inputs and arithmetic

The host allowance is 350 mA. Auxiliary allowances are detector 30 mA, SHT40
breakout 5 mA, OLED 40 mA and reserve 10 mA. **All are design allocations, not
vendor maxima or measurements.** Heater remains disabled in the firmware.
The 25% auxiliary margin gives 106.25 mA; input allowance becomes 456.33 mA,
including 0.08 mA regulator quiescent current. That leaves only 43.67 mA against
the chosen 500 mA planning budget; startup peaks may exceed it.

The [AP2112 datasheet, DS39724 Rev 2-2](https://www.diodes.com/datasheet/download/AP2112.pdf)
lists 80 uA maximum no-load quiescent current under its stated test conditions,
600 mA output rating and 184 C/W SOT25 junction-to-ambient reference. Those values
do not characterize an arbitrary breakout. This calculator accepts 4.3–6 V for
the fixed 3.3 V reference design; it does not model dropout or transient response.

At nominal 5 V, LDO loss is `(5 - 3.3) * 0.10625 + 5 * 0.00008 = 0.181025 W`.
Using the datasheet thermal reference at an assumed 40 C ambient gives about
73.3 C junction. At a 5.25 V scenario, the estimate increases to 78.2 C. The
100 C review threshold is a chosen engineering screen, not a touch-temperature
limit. Enclosed air, copper area and adjacent heat make these estimates uncertain.
Neither the regulator's maximum current nor its thermal shutdown approves the
assembled unit. Do not use shutdown as normal temperature control.

The [DFRobot module specification](https://wiki.dfrobot.com/sen0463/) lists its
low-voltage input range but does not provide a worst-case input current in the
reviewed table. Therefore the detector's 30 mA allowance still needs measurement.

## Supply and power-off boundaries

- The 500 mA number is a planning budget, not evidence of USB enumeration,
  Type-C current advertisement or port entitlement. Use an appropriately rated,
  current-limited source and verify the exact MCU board's USB/5 V path.
- Do not back-power the MCU through GPIO, I2C or count output. Disconnect both
  USB and any separate pulse fixture before changing connections.
- Do not tie auxiliary 3.3 V to the board regulator output. Breakout LEDs and
  regulator variants can change real consumption.
- AP2112 output discharge does not establish that the detector's internal high
  voltage is discharged. Keep its original enclosure closed even after USB is
  removed; no safe internal access waiting time is asserted.
- No battery, charger or custom high-voltage circuit is authorized by this draft.

## Bench lesson (45–60 minutes, only after wiring review)

Start without the detector connected. Check polarity and rails, then use the
low-voltage pulse fixture. Log current at startup, idle, full-white OLED and
normal operation. Power off before adding the intact detector. Measure supply
current and breakout surface temperature without opening or touching its HV area.
Do not deliberately short the supply or block ventilation as a classroom test.

| Record | Result |
| --- | --- |
| Source model, current limit, cable, actual voltage | pending |
| Exact MCU / OLED / regulator breakout revisions | pending |
| Startup peak current and measurement bandwidth | pending |
| Host current; each auxiliary current; full-white OLED | pending |
| Ambient; regulator surface; 10/30/60-minute temperature | pending |
| Auxiliary rail minimum during transitions / oscilloscope evidence | pending |
| Enclosure closed versus open environmental-reading bias | pending |
| Reviewer disposition / revised allowances | pending |

Update measured evidence separately from planning inputs. A budget passing does
not authorize powered use of unreviewed mechanical packaging.

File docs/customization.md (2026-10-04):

# Customization guide

IonTrail One is intended to be both a product and a development platform. The pulse-counting core stays small so customers can build new experiences around it without changing time-critical interrupt code.

## Recommended extension points

### Display and interaction

Keep UI code in the application layer under `src/`. A custom screen can read `cpm()`, `totalCounts()`, and `lastWindowMs()` after `hasFreshReading()` returns true. Themes should keep the count rate visible and avoid unsupported “safe” or “danger” labels.

### Feedback

Drive a low-current LED directly only if it is within the ESP32 pin limits. Use a transistor or suitable driver for buzzers and larger loads. Provide independent controls for click sound, LED pulse, and alarm behavior so the device remains discreet on a bag.

### Environmental sensors

The provisional board map reserves an I2C bus for an SHT40 and display. Additional sensors can share the bus if their addresses and power requirements are compatible. Avoid placing a temperature sensor next to the ESP32 regulator, charger, battery, or display where self-heating biases the result.

### Bluetooth Low Energy

A companion app can expose live CPM, total counts, temperature, humidity, battery status, device information, and user settings. Keep firmware updates authenticated and clearly separate experimental characteristics from stable ones.

### Logging and integrations

Store timestamps, CPM/CPS, raw counts, sampling window, battery state, environmental readings, hardware revision, firmware version, and calibration profile. Including metadata makes exported CSV or JSON data scientifically more useful.

### Tube profiles

A tube profile may contain the tube model, operating voltage range, plateau information, dead-time configuration, calibration provenance, date, and uncertainty. Do not ship one universal CPM-to-dose constant.

## API stability

The SDK is pre-1.0 while the product is in EVT. Releases may change pins and APIs. Customer projects should pin a tagged SDK version once releases begin. Breaking changes will be called out in release notes.

## Hardware customization boundary

Changing screens and data handling is low risk. Changing the GM high-voltage supply, tube bias, pulse interface, battery charger, or mechanical guard requires competent engineering review and validation. See [hardware](hardware.md) and [safety](safety.md).

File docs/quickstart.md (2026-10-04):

# SDK quick start

This guide brings up the count-rate SDK on an ESP32-C3 SuperMini without requiring the display, environmental sensor, or final enclosure.

## What you need

- ESP32-C3 SuperMini or compatible ESP32-C3 development board
- USB data cable
- A GM pulse source that presents a clean **3.3 V logic signal**
- Visual Studio Code with PlatformIO

> Do not attach a GM tube or high-voltage output directly to the ESP32. Use an isolated or properly conditioned, current-limited pulse interface.

## Build the reference firmware

```bash
git clone https://github.com/Kelvinchan324/IonTrail-One.git
cd IonTrail-One
pio run
pio run --target upload
pio device monitor
```

The serial monitor should print one CPM result per sampling window.

## Confirm the board map

Open `include/iontrail_board.h` and compare every pin with the labels and schematic for your specific SuperMini revision. The file is a provisional EVT map, not a promise that all boards sold under the same name are identical.

The GM pulse input must:

- remain between 0 V and 3.3 V;
- idle at the level expected by `interruptMode`;
- have a clean edge and adequate pulse width;
- share a valid logic reference with the ESP32; and
- be protected against transients from the high-voltage section.

## Use the library in your own sketch

```cpp
#include <IonTrail.h>

IonTrailDevice detector;

void setup() {
  Serial.begin(115200);

  IonTrailConfig config;
  config.gmPulsePin = 3;
  config.sampleWindowMs = 10000;
  detector.begin(config);
}

void loop() {
  detector.update();
  if (detector.hasFreshReading()) {
    Serial.printf("%.1f CPM\n", detector.cpm());
  }
}
```

Start with `deadTimeMicros = 0`. Add dead-time rejection only after characterizing the chosen tube and pulse-conditioning circuit.

## Next steps

- Adapt the [basic counter example](../examples/basic_counter/basic_counter.ino).
- Review [customization](customization.md) before adding screens or BLE services.
- Read [safety and calibration](safety.md) before interpreting measurements.

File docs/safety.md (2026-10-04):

# Safety, calibration and product claims

## Intended use

IonTrail One is planned as an educational and environmental-monitoring instrument. It can make count-rate changes visible and help users log experiments. It is not a certified personal dosimeter, contamination survey meter, medical device, emergency instrument, or proof that an environment is safe.

## High voltage

GM tubes commonly operate at several hundred volts. Even a low-current supply can damage electronics, cause a startling shock, or retain charge. Product hardware needs current limiting, appropriate creepage and clearance, a discharge path, insulation, protected pulse conditioning, and a mechanically inaccessible high-voltage region. Only trained people with suitable equipment should work on the energized detector circuit.

## Battery and charging

Use a protected cell from a traceable supplier. Product hardware should monitor temperature, limit charging current to the cell specification, behave safely while operating from USB, and prevent reverse polarity, overcharge, over-discharge, and short-circuit faults. Do not enclose an unvalidated prototype battery in a consumer product.

## Count rate versus dose rate

CPM and CPS are direct instrument outputs. A dose-rate estimate depends on the tube, radiation type and energy, geometry, enclosure attenuation, electronics, calibration reference, and uncertainty. A constant copied from an unrelated counter is not valid evidence.

If a dose estimate is enabled, the UI and exported data should identify the tube profile, calibration source and uncertainty, and should continue to expose raw count-rate data.

## Alarm behavior

An alarm threshold is a user notification, not a safety verdict. Document its units, averaging interval, persistence and reset behavior. Test failure modes including an unplugged tube, saturated input, low battery, crashed firmware, muted sound and stuck button.

## Regulatory review

Before sale, obtain qualified advice for each destination market. Likely areas include product electrical safety, radio/EMC, battery transport, chemical/material restrictions, labeling, waste/recycling, consumer protection, privacy for connected features, and the claims made in advertising and instructions.

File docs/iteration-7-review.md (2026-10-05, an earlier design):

# Iteration 7 — bounded OLED availability recovery

5 October 2026. USB bench firmware draft; no detector, screen or bus connected.

An absent/failed OLED previously remained unavailable until reboot. The running
loop now probes its address once per two-second period and retries initialization
only while unavailable. A live display is not repeatedly initialized. A detected
loss suspends drawing; return requires successful begin and a post-init ACK.
Transition comments preserve the existing CSV schema. Count processing still
precedes optional display service, and UI time refreshes after synchronous I/O.

Pinned Adafruit SSD1306 2.5.17 implementation reviewed locally and against the
upstream version: existing framebuffer is reused, shared-Wire setup can remain
owned by the app, but drawing does not return a transfer success acknowledgement.
See [driver basis and physical gaps](display-recovery.md#driver-basis-and-limits).
We do not equate address presence with correct pixels or detector health.

Production-main-loop native tests now cover boot absence, init failure, retry
cadence/no catch-up burst, no live reinitialization, detected loss, post-init ACK
loss, recovery, delay versus count timestamp, transition comments and rollover.
The first test incorrectly expected immediate drawing on recovery; it was
corrected to the existing scheduled 500-ms refresh behavior, not hidden by a
firmware timing change. Vendor methods and I2C results remain scripted doubles.

Verification: application, counter and climate native tests pass; 54 pytest tests
pass, including a new CSV transition-comment case. Power-budget check remains a
planning calculation. ESP32-C3 build passes: RAM 14,648 bytes, flash 282,300 bytes.
No dependency, pin, count schema, CAD, power or detector-guard changes. New remote
CI result was not yet checked at commit time. No website deployment performed.

Still unverified: actual display/clone identification, pixel/layout quality,
power-loss recovery, wrong-device ACK, silent resets, retry heap/stack use,
shared-bus faults and count throughput during I/O. A two-second poll is not a
guaranteed detection latency or independent watchdog. Synchronous driver calls
can delay the loop; stale pixels cannot be trusted as current data. The README
now links a synthetic exercise and unfilled physical validation plan. Power off
before changing wiring; do not hot-plug the detector or open its HV guard.

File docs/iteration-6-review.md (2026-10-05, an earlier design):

# Iteration 6 — visual enclosure handoff

5 October 2026. Review graphic and documentation; no physical enclosure built.

Added an exploded STEP-derived view and a labelled XY component-envelope plan.
Lid displacement of +35 mm is presentation-only; no STEP/STL source was modified.
The renderer checks nine bodies against the saved assembly one-to-one by volume
and bounds, and checks the lid datum against the editable enclosure parameters.
It derives lid dimensions/closed height from geometry, not copied drawing text.
The assumed factory guard envelope remains explicitly labelled as assumed.

Visual review confirmed the figure communicates component positions and the
current missing design work: reset button access through the closed lid, positive
module retention, verified guard dimensions, cable strain relief and underside
feet. Corrected an initial axis-caption overlap. Transparencies and wall omission
are labelled; no isolation rating, touch-access assessment or material claim.

Verification: nine-body render matching pass, final PNG visually inspected,
53 Python tests pass (two new freshness checks), scoped Ruff and whitespace
checks pass. Existing Python CI automatically includes the new tests without CAD
dependencies. Input hashes normalize text line endings; image/STEP use native
bytes. Source ledger includes generator versions and script hash. This revision's
remote CI must be checked after push. No firmware/dependency change or new build
claim; no board flashed, detector powered or guard opened.

Physical safety/retention and calibration remain unresolved. The graphic is a
review aid rather than a dimensioned manufacturing drawing or finished product.

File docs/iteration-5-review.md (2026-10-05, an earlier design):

# Iteration 5 — production application-loop coverage

5 October 2026. Engineering draft; no firmware flashed or hardware connected.

Added a strict-warning native integration binary that compiles actual `setup()`
and `loop()` with the production counter. New test doubles sit exclusively under
`tests/native`: scripted Wire presence, SHT4x initialization/read outcomes and
delay, serial capture and SSD1306 text capture. No production behavior was changed.

Verified boot settings, completed-window CSV cadence/arithmetic, climate boot
absence and retry, failed initialization, failed/invalid readings and recovery,
delayed I/O timestamp handling, reset threshold and one-per-hold behavior,
pending pulse discard, counter initialization failure and clock rollover.
The test initially expected immediate display refresh after reset; corrected it
to respect the production 500-ms UI schedule. No firmware defect was inferred
from that test timing mistake.

Local verification: native application, counter and climate tests pass; Python
CSV/power suite passes (51 cases). Application test uses -Wall -Wextra -Werror
and is added to Engineering checks. Remote CI must be checked after push.
Embedded production sources/dependencies unchanged; no new embedded build claim.

Remaining: real Adafruit/I2C behavior and electrical fault tests, OLED rendering,
physical module retention/dimensions and current/heat measurements, detector
calibration. OLED boot absence still requires restart after a power-off fixture
change; no automatic reconnect is implemented. Simulated text is not pixel QA.
The README now links the application lesson and blank physical-evidence table.

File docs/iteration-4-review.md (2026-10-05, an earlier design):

# Iteration 4 — climate availability and log consistency

5 October 2026. No board flashed, sensors connected, or physical tests performed.

Implemented a shared climate reading helper: failed/nonfinite/out-of-range-RH
measurements invalidate both values; cached display readings expire after 15 s;
only a successful new reading restores availability. Boot-time sensor absence
is retried once per completed counter window, while initialized drivers use
ordinary read retries. Removed the counter-init early return so the available
OLED can show INIT FAIL rather than remain on an initial screen.

CSV header unchanged. Offline validation now checks climate availability fields
when present, rejects incomplete climate headers and duplicate columns, and
keeps legacy counter-only capture support. README and the new
[climate lesson](climate-validity.md) distinguish absence from zero, sample age
from accuracy, and climate status from radiation detector health.

Verification:

- 51 Python tests pass (38 CSV cases and 13 power-budget cases); scoped Ruff passes.
- New native climate helper tests pass with `-Wall -Wextra -Werror`.
- Pinned ESP32-C3 firmware builds: RAM 14,648 bytes, flash 282,034 bytes.
- CI includes the climate helper test; new remote result remains to be checked.
- These tests do not exercise the full main loop, physical I2C retries, OLED
  text layout on hardware or fault recovery under a stuck bus.

Unfinished: hardware identification/retention, thermal and signal measurements,
real sensor calibration comparison, display reconnection, independent fault
supervision, and guarded-detector validation. The product remains an untested
engineering draft, not a safety instrument or calibrated dosimeter.

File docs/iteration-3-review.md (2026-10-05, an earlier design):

# Iteration 3 — bench cover and low-voltage budget

2026-10-05. Still an untested engineering draft; not a pocket product or safety meter.

## Delivered

- Parametric secondary tray/lid around the existing fixture and intact guarded
  module allowance. Editable STEP/STL and a nine-solid assembly STEP.
- Four fixture supports, four external lid ears, provisional USB opening and
  vents over the climate-sensor bay. No holes in the original detector enclosure.
- Machine-readable planning loads and a reproducible budget checker; nominal
  current allowance 456.33 mA, auxiliary allocation with margin 106.25 mA.
- Material/retention/clearance and power/thermal worksheets, README teaching links.
  BOM regenerated with tray, lid and lid-fastener candidates (16 rows total).

## Evidence

- 34 Python tests pass, including 13 power-budget cases; scoped Ruff checks pass.
- Nominal budget inequalities pass. Estimated LDO loss 0.181025 W; reference
  junction estimate 73.309 C at assumed 40 C ambient. These are not measurements.
- CAD checks: each part is one valid positive-volume solid; no intrusion into
  component envelopes or the fixture; individual and assembly STEP reimport pass.
  Assembly has nine solids. Lid footprint 202 x 107 mm, nominal cover height
  53.5 mm before unresolved feet/fastener projections.
- No embedded firmware changes in this iteration. No new firmware/hardware
  execution claim; existing counter tests and build remain covered by CI.

## Next gates

1. Measure the intact factory guard and its permitted retention interfaces. The
   published board dimensions do not certify the assumed guard envelope.
2. Resolve positive module retention, cable strain relief, USB mating and feet.
   The count-reset button is inaccessible under this lid until an actuator is designed.
3. Select verified material, lid transparency and fastener lengths; assess
   touch access, deflection, electrical insulation, flammability and drop behavior.
4. Measure startup/full-white display/normal current and enclosed heat rise;
   current allocations are guesses for planning, not worst-case vendor ratings.
5. Complete physical pulse-injection and background-count records. Enclosure
   material may alter detector response; no calibrated-dose claim follows.

Verdict: substantive packaging and power draft, **not fabrication/power-up approval**.

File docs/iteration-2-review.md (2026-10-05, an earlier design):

# Engineering review — iteration 2, 5 October 2026

Disposition: **software draft improved; physical build gates remain open**.

## Findings and corrections

- Optional dead-time filtering previously used a zero timestamp as though a pulse
  had already occurred. An explicit first-pulse flag now accepts the first event,
  including at microsecond zero after startup/reset.
- ISR timestamp, pending count and reset state now share the same critical section.
  Tests check logic and balanced lock calls, not real simultaneous execution.
- Pending and total counts no longer silently wrap. Overflow latches a fault;
  CSV validity and display FAULT expose it. Reset starts a new measurement.
- The device now owns its interrupt explicitly, releases it with end/destruction,
  rejects a second active instance and is not copyable.
- CSV includes window_counts and counts_valid. Offline validation checks elapsed
  time, raw-count CPM arithmetic, contiguous totals and uptime, including rollover.
- Tested sensor-library versions are pinned in PlatformIO.
- README troubleshooting, test guide and blank bench worksheet added.
- AP2112 SOT25 pin mapping checked against manufacturer DS39724 Rev. 2-2;
  assembled breakout selection/order and thermal measurements remain unresolved.

## Evidence obtained

| Check | Result | Boundary |
| --- | --- | --- |
| Python CSV validator | 21 passed | Synthetic captures only |
| Native production counter library | PASS | Mock GPIO/time, no concurrent interrupt model |
| ESP32-C3 firmware | Compile PASS | RAM 14,640 bytes; flash 281,822 bytes |
| Previous engineering GitHub workflow | PASS, commit 948a4ed | New commit's remote result still to be checked |

Native cases: 10 Hz count rate; real elapsed interval after delayed update;
zero-count interval; pending-data reset; first pulse; exact dead-time boundary;
micros/millis rollover; invalid interval configuration; ownership and destructor;
saturating arithmetic at uint32 limits.

No physical pulse-rate sweep, detector response, thermal or electrical test
has been performed. Arithmetic overflow detection does not detect missed pulses,
tube dead time, disconnected sensors or unsafe environmental conditions.

## Next priorities

1. Parameterized enclosure/guard-retention draft around the intact vendor module,
   with fabrication gates for actual mounting/guard dimensions.
2. Resolve exact MCU/display/regulator breakout procurement and connector schedule.
3. Verify power-off signal interactions and thermal/current budget on hardware.
4. Run the blank bench worksheet with instruments; preserve raw logs and failures.
5. Expand firmware-facing failure tests and measured interrupt-throughput evidence.

The pre-existing product-page deployment workflow failed on both iteration 1 and
its predecessor. No deployment settings were changed or rerun.

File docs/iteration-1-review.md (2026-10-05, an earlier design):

# Engineering review — iteration 1, 5 October 2026

Disposition: **continue; educational bench draft, not a calibrated safety instrument**.

## Delivered

- ESP32-C3 pulse-counting firmware with SHT40, optional SSD1306, status LED,
  hold-to-reset button and elapsed-time-based CPM CSV output.
- Intact SEN0463 module architecture; no custom high-voltage generator design.
- 13-row BOM, 11-net module schematic, six placement envelopes, editable manifest,
  drilled fixture STEP/STL and re-importable layout STEP.
- Pulse-injection fixture source and CSV checker; README/manual and five lessons.

## Evidence actually obtained

- PlatformIO 6.2.0 / Espressif32 6.10.0: esp32-c3-supermini compile PASS.
  RAM 14,632 bytes; flash 281,564 bytes at this iteration.
- CSV checker: four pytest tests PASS (synthetic data only).
- CadQuery 2.8.0: valid positive-volume fixture; seven layout solids re-imported.
- Manifest connection/geometry checks PASS. CI added; remote result pending push.

No actual pulse generator, detector, environmental sensor or enclosure was tested.
No CPM-to-dose factor, isotope identification or radiation protection claim is made.

## Next iteration, in priority order

1. Test the actual interrupt/counting library with a host time/GPIO shim, including
   reset, dead-time rejection and timer rollover; review shared ISR state.
2. Verify exact regulator package/pinout and rail budget; resolve generic board
   and display supplier choices, connector ordering and power-off interactions.
3. Replace layout-only guard with a parameterized, ventilated enclosure draft,
   explicitly gated by measured detector clearances and mounting dimensions.
4. Extend CSV validation to elapsed windows/count increments; pin software deps.
5. Physical owner: injected-pulse accuracy, missing sensor behavior, safe intact
   detector handling, current/temperature measurements and guarded assembly review.

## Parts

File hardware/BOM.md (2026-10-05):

# IonTrail One EVT-A — bill of materials

USB-powered educational bench instrument using intact guarded SEN0463. No internal battery or custom high-voltage circuitry.

Prices and procurement approval are not supplied. Quantities are per prototype.

| Ref | Qty | Selection / value | Selection status | Source |
| --- | ---: | --- | --- | --- |
| U1 | 1 | ESP32-C3 SuperMini module | Provisional board revision; verify pins before assembly | [Design rationale](../docs/engineering.md) |
| J1 | 1 | USB data and 5 V cable | Prototype selection; bench verification required | [Design rationale](../docs/engineering.md) |
| U2 | 1 | AP2112K-3.3 LDO on breakout | Auxiliary sensors only; do not join to MCU 3V3 output | [Diodes AP2112](https://www.diodes.com/part/view/AP2112/) |
| C1 | 1 | 10 uF ceramic / >=10 V | Prototype selection; bench verification required | [Design rationale](../docs/engineering.md) |
| C2 | 1 | 10 uF ceramic / >=10 V | Prototype selection; bench verification required | [Design rationale](../docs/engineering.md) |
| U3 | 1 | DFRobot SEN0463 guarded detector | 107 x 42 mm board; larger guard envelope assumed | [DFRobot SEN0463](https://wiki.dfrobot.com/sen0463/) |
| R1 | 1 | 1k pulse series resistor | Not a high-voltage isolation component | [Design rationale](../docs/engineering.md) |
| U4 | 1 | SHT40 Adafruit breakout | Address 0x44; vented end; envelope assumed | [Adafruit SHT40](https://learn.adafruit.com/adafruit-sht40-temperature-humidity-sensor/pinouts) |
| U5 | 1 | SSD1306 128x64 I2C OLED | Select 3.3 V compatible module at 0x3C; verify pin order | [Adafruit SSD1306 library](https://github.com/adafruit/Adafruit_SSD1306) |
| S1 | 1 | Momentary reset-count button | Firmware: hold two seconds; internal pull-up | [Design rationale](../docs/engineering.md) |
| R2 | 1 | 1k status LED resistor | Prototype selection; bench verification required | [Design rationale](../docs/engineering.md) |
| D1 | 1 | Green indicator LED | Heartbeat only, not detector-health indication | [Design rationale](../docs/engineering.md) |
| H1 | 4 | M3 fixture screw + nut + washer set | Four plate/tray through-bolts; length TBD from 13 mm stack plus nut/washers; no guard retention | [Design rationale](../docs/engineering.md) |
| H2 | 1 | Secondary bench tray draft | Editable STEP/STL; material and protective performance unverified | [Enclosure review](../mechanical/README.md) |
| H3 | 1 | Secondary bench lid draft | Transparent material candidate; 2.5 mm thickness, no protective rating | [Enclosure review](../mechanical/README.md) |
| H4 | 4 | M3 lid through-bolt + nut + washer set | 3.4 mm holes; candidate M3x16 length requires stack and tool-access verification | [Enclosure review](../mechanical/README.md) |

## Net connections

Identical labels in the schematic are electrically connected.
NC means intentionally unconnected. Supply and connector ratings need physical verification.

- **USB_HOST**: U1.USB, J1.USB
- **USB_5V**: U1.5V, U2.1 VIN, U2.3 EN, C1.1
- **GND**: U1.GND, J1.GND, U2.2 GND, C1.2, C2.2, U3.-, U4.GND, U5.GND, S1.2, D1.K
- **COUNT_IN**: U1.GPIO3, R1.2
- **SDA**: U1.GPIO4, U4.SDA, U5.SDA
- **SCL**: U1.GPIO5, U4.SCL, U5.SCL
- **RESET_BTN**: U1.GPIO0, S1.1
- **LED_ANODE**: U1.GPIO7, R2.1
- **AUX_3V3**: U2.5 VOUT, C2.1, U3.+, U4.VIN, U5.VCC
- **PULSE_MODULE**: U3.D, R1.1
- **LED_LIMITED**: R2.2, D1.A

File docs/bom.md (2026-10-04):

# Prototype bill of materials

These links intentionally open Taobao searches rather than single listings. Listings are volatile, and a permanent SDK should not silently endorse an unknown seller. Confirm dimensions, documentation, seller history and return terms before ordering.

| Component | Search | Selection notes |
| --- | --- | --- |
| ESP32-C3 SuperMini | [Taobao search](https://s.taobao.com/search?q=ESP32-C3%20SuperMini%20%E5%BC%80%E5%8F%91%E6%9D%BF) | Confirm pin labels, USB interface, regulator and schematic for the exact revision. |
| J305βγ GM tube | [Taobao search](https://s.taobao.com/search?q=J305%CE%B2%CE%B3%20%E7%9B%96%E9%9D%A9%E7%AE%A1) | Request operating-voltage and plateau data; inspect packaging and tube condition. |
| SBM-20 GM tube | [Taobao search](https://s.taobao.com/search?q=SBM-20%20%E7%9B%96%E9%9D%A9%E7%AE%A1) | Useful comparison candidate; authenticity and history may be uncertain. |
| 400 V GM module with pulse output | [Taobao search](https://s.taobao.com/search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) | Require schematic or credible interface documentation; verify output before the ESP32. |
| SHT40 breakout | [Taobao search](https://s.taobao.com/search?q=SHT40%20%E6%B8%A9%E6%B9%BF%E5%BA%A6%20%E6%A8%A1%E5%9D%97) | Prefer a documented 3.3 V board and allow airflow around the sensor. |
| 0.96-inch SSD1306 OLED | [Taobao search](https://s.taobao.com/search?q=0.96%20OLED%20SSD1306%20I2C%203.3V) | Confirm controller, I2C address, voltage and exact outline. |
| Protected 603040 LiPo with NTC | [Taobao search](https://s.taobao.com/search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) | Size is a starting envelope only. Require traceability and cell documentation. |
| TP4056 USB-C charging board | [Taobao search](https://s.taobao.com/search?q=TP4056%20Type-C%20%E5%85%85%E7%94%B5%20%E4%BF%9D%E6%8A%A4%E6%9D%BF) | Suitable for selected bench prototypes, not the final product architecture. |
| Mini carabiner | [Taobao search](https://s.taobao.com/search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) | Test gate size, sharp edges, finish and pull load. Not climbing equipment. |
| Smoked transparent polycarbonate | [Taobao search](https://s.taobao.com/search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) | Prefer impact-resistant PC over brittle acrylic for a carried product. |

For a sellable revision, safety-critical and performance-critical parts should come from authorized or otherwise traceable sources with controlled specifications. Requalify any supplier or component change.

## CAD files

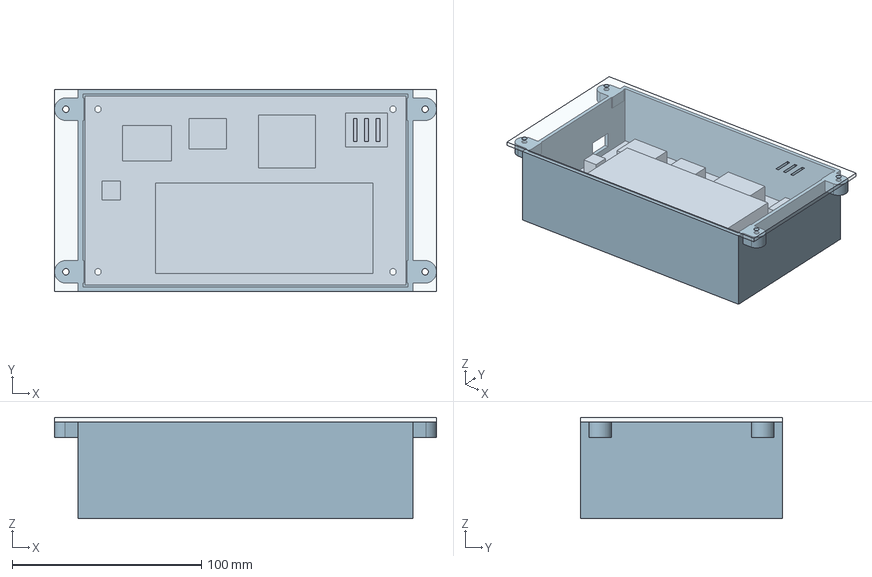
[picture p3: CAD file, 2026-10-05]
mechanical/enclosure-layout.step
202.0 x 107.0 x 53.5 mm
tray
lid_candidate
fixture
U1_ENVELOPE
U2_ENVELOPE
U3_ENVELOPE
U4_ENVELOPE
U5_ENVELOPE
S1_ENVELOPE

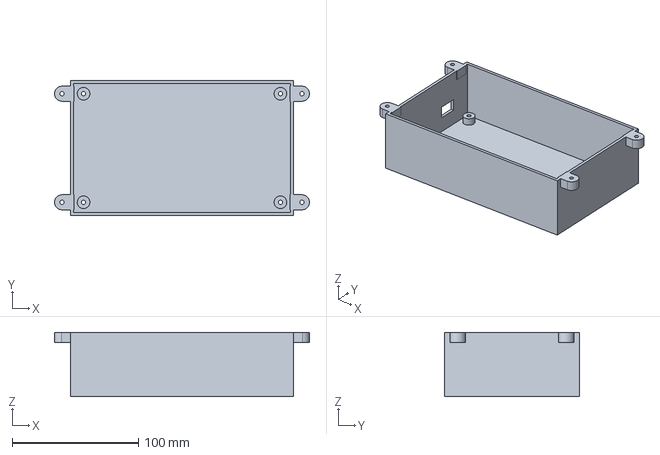
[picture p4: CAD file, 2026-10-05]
mechanical/bench-tray-draft.step
202.0 x 107.0 x 51.0 mm

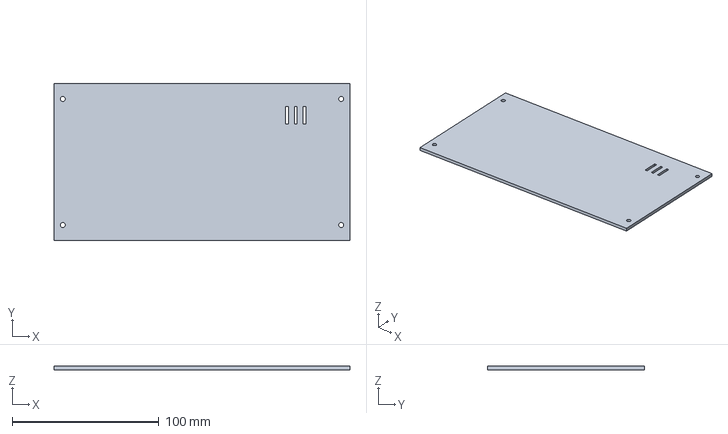
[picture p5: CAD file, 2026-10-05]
mechanical/bench-lid-draft.step
202.0 x 107.0 x 2.50 mm

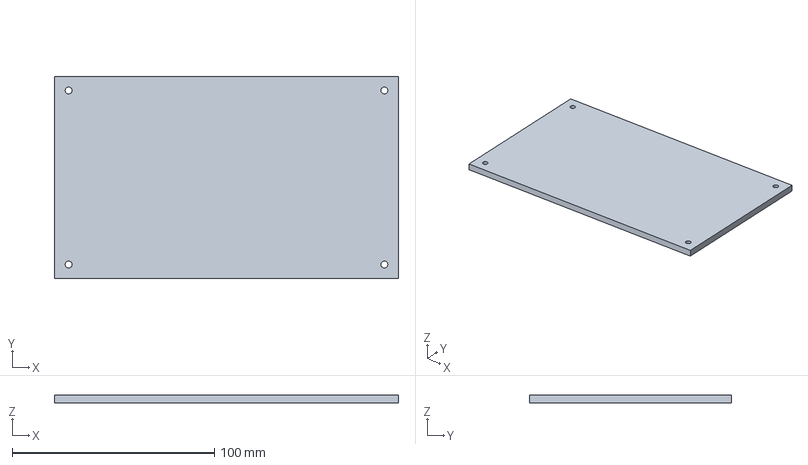
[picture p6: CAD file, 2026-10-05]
mechanical/fixture-plate.step
170.0 x 100.0 x 4.00 mm

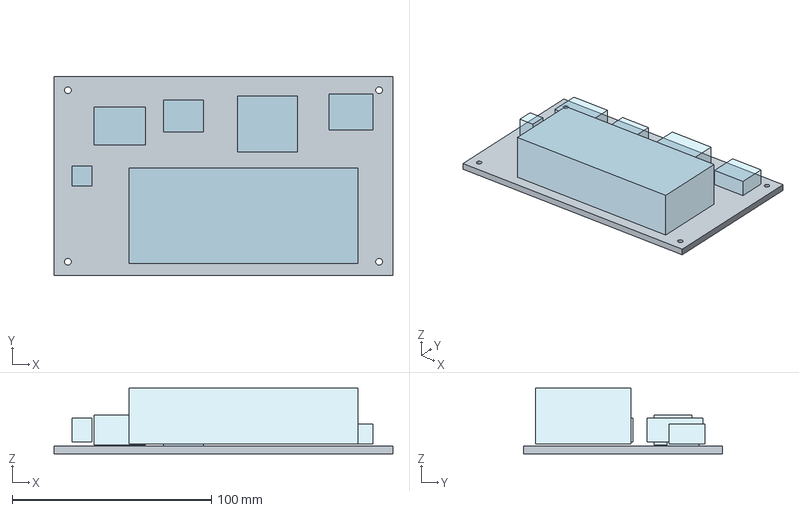
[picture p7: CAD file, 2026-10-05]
mechanical/layout-draft.step
170.0 x 100.0 x 33.0 mm
fixture_plate
U1_ENVELOPE
U2_ENVELOPE
U3_ENVELOPE
U4_ENVELOPE
U5_ENVELOPE
S1_ENVELOPE

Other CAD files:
mechanical/bench-lid-draft.stl
mechanical/bench-tray-draft.stl
mechanical/fixture-plate.stl

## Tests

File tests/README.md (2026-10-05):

# Verification without connected hardware

Run the CSV validation tests from the repository root:

```sh
python -m pip install pytest==9.1.1
python -m pytest tests
python tools/check_power_budget.py
```

Run the **production counter implementation** against a minimal host GPIO/time shim:

```sh
c++ -std=c++17 -Itests/native -Ilib/IonTrail/src tests/native/test_counter.cpp lib/IonTrail/src/IonTrail.cpp -o /tmp/iontrail-tests
/tmp/iontrail-tests
```

On Windows an optional compiler is available through
`python -m pip install ziglang==0.13.0`; replace `c++` with
`python -m ziglang c++` and choose an output under ignored `build/`.
Compile firmware separately with `pio run`.

The counter test also rejects negative/oversized GPIO numbers (including values
that would wrap to GPIO3), level/change/disabled/wakeup interrupt modes and other
invalid integers. Rejection is checked before GPIO side effects and must preserve
the active interrupt, pending counts, previous reading and measurement epoch.
Both accepted edge modes and the C3 numeric pin boundaries are exercised. This
does not approve board-reserved pins or test the actual ESP32 interrupt service.

The actual starter sketch is compiled and exercised for a valid reading and an
occupied-counter initialization failure:

```sh
c++ -std=c++17 -Wall -Wextra -Werror -Itests/native -Ilib/IonTrail/src tests/native/test_basic_example.cpp lib/IonTrail/src/IonTrail.cpp -o /tmp/example-tests
/tmp/example-tests
```

The production climate-availability helper has an independent native test:

```sh
c++ -std=c++17 -Iinclude tests/native/test_climate.cpp -o /tmp/climate-tests
/tmp/climate-tests
```

It checks finite values, RH range, failed-read invalidation, the 15-second age
boundary, deliberate successful recovery and clock rollover. It does not execute
real I2C, the full main loop, OLED drawing, or vendor-driver initialization/retry.
Python CSV checks verify consistency of `sensor_ok` and climate fields when
present; legacy counter-only captures remain supported. Neither set of tests
measures environmental accuracy or establishes Geiger-module health.

## Production application-loop integration

```sh
c++ -std=c++17 -Wall -Wextra -Werror -Itests/native/app -Itests/native -Iinclude -Ilib/IonTrail/src tests/native/test_app.cpp lib/IonTrail/src/IonTrail.cpp -o /tmp/app-tests
/tmp/app-tests
```

This compiles the actual `src/main.cpp` setup/loop and production counter library.
Test-only doubles replace the GPIO/time, serial, Wire, SHT4x and SSD1306 boundaries;
they are not included in the embedded build. Cases cover startup pin/bus settings,
one CSV row per count window, climate boot absence/begin failure/read failure and
recovery, invalid humidity, delayed synchronous reads, reset hold/release and
discarded pending counts, counter-init failure, and clock rollover. It checks
display text after its scheduled 500-ms update, not immediately after each loop.

OLED cases now cover boot absence, bounded two-second retries, allocation/init
failure, detected loss, post-initialization ACK loss, recovery without repeated
live-driver initialization, no burst catch-up, synchronous retry delay, unchanged
count-window timestamps and uint32 rollover. Native text
capture does not render fonts, clipping, pixels, or actual I2C transfers. Driver
initialization/read behavior is scripted, not the real Adafruit implementation.
These tests are not a bus-hang watchdog, electrical fault injection, simultaneous
interrupt model, hardware reset test, or proof of detector health. No physical
measurement results are filled by the automated tests.

The power-budget tests check planning arithmetic, overload scenarios, invalid
numbers and input range. They do not provide measured current or temperature.
See [the power worksheet](../docs/power-review.md). To check draft solids locally,
install CadQuery 2.8.0 and run `python tools/build_enclosure.py`; CAD fit checks
use assumed component envelopes and are not included in the lightweight CI job.

The Python suite also checks `mechanical/enclosure-visual-review.json` input and
image hashes. Regenerate using `python tools/render_enclosure_review.py` with
CadQuery 2.8.0 and Matplotlib 3.11.2, then visually inspect before committing.
The renderer matches nine input bodies to the saved assembly by volume/bounds;
lightweight CI verifies freshness only, not CAD fit or electrical guarding.

The tests cover elapsed-window rate calculation, first-pulse/dead-time behavior,
reset of pending data, timer rollover, interrupt ownership, destruction and the
overflow arithmetic helper. They do not simulate simultaneous threads or prove
maximum interrupt throughput. Pending-counter overflow needs a hardware/fault
injection test; the helper test does not claim billions of physical interrupts.
Call foreground methods from one loop/task only. Do not destroy/reconfigure the
device concurrently with another foreground task.

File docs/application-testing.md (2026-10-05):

# Application behavior lesson — no hardware required

The native application test exercises the production firmware's `setup()` and
`loop()` with a real counter implementation and test-only board/driver doubles.
Use the [test instructions](../tests/README.md#production-application-loop-integration)
to compile and run it. Do not flash the host test doubles to a board.

## What to inspect

| Scenario | Expected application behavior |
| --- | --- |
| No completed count window | OLED text is WAIT; no numeric CSV row yet |
| Ten injected events in a 10-second window | 10 window counts, 60 CPM, total 10; synthetic only |
| Climate sensor absent at boot | Counts continue; climate fields NaN, sensor_ok 0; retry once per completed window |
| Climate initialization still fails | No getEvent call; next completed window retries initialization |
| Initialized climate read fails or humidity exceeds 100 | Previous climate numbers invalidated; next successful read can recover without begin |
| Simulated read takes 600 ms | CSV uptime remains count-window endpoint; display checks climate against the refreshed clock |
| Button low for less than 2000 ms | No totals reset |
| Button low for at least 2000 ms | One reset per uninterrupted hold; pending pulses discarded; new full window required |
| Counter cannot own the interrupt at setup | INIT FAIL display text; no numeric CSV rows |
| OLED absent at boot | Serial/counting still operate; probe/init retry every two seconds |
| OLED stops acknowledging | Suspend drawing at the next scheduled probe; emit one transition comment |
| OLED returns or init failure clears | Reinitialize without restarting shared Wire; require post-init ACK |

After a reset, the visible WAIT message appears on the next scheduled display
refresh, nominally within 500 ms **if the loop and I2C calls keep running**.
This is not a measured display response time. If the loop stalls, the screen can
retain old text. The LED similarly indicates only foreground-loop activity.
The [display-recovery lesson](display-recovery.md) covers retry timing, delayed
initialization and the distinction between an address ACK and visible pixels.

## Teaching exercise

1. Run the test unchanged and record the PASS result as **host simulation**.
2. Read the `freshBoot(false, false)` section in the test. Identify which checks
   prove counting still works with the optional modules unavailable.
3. Find the delayed-read case. Explain why climate time and count-window endpoint
   are different, and why a fresh clock read is required before rendering.
4. Find the reset case. Explain why held buttons cannot repeatedly erase totals,
   and why a new full window is needed before another rate is reported.
5. Identify the external behaviors these doubles cannot prove: actual driver
   retry behavior, bus electrical faults, latency, pulse throughput and pixel layout.

## Separate physical evidence record — all pending

Use an approved low-voltage fixture and the existing
[bench procedure](bench-record.md) and [climate procedure](climate-validity.md).
Keep the detector's factory high-voltage guard intact. Do not short live bus lines
or improvise fault injection on a powered detector assembly.

| Item | Required evidence | Result |
| --- | --- | --- |
| Exact board/module identification | Revision, photos, verified pins and supply | Pending |
| Missing optional modules at cold boot | Power-off reconfiguration; saved serial capture | Pending |
| Supported climate recovery fixture | Reviewed setup and captured results | Pending |
| Reset button operation | Measured hold, release, new window and display response | Pending |
| OLED layout/readability | Actual 128x64 screen photographs, including INIT FAIL | Pending |
| Loop/bus timing | Measured latency and stop/stall behavior | Pending |

Passing host tests does not make IonTrail a calibrated dose instrument or a
personal safety meter. Zero counts still cannot establish detector health.

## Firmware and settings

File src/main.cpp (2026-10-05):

#include <Arduino.h>
#include <Wire.h>
#include <Adafruit_SHT4x.h>
#include <Adafruit_SSD1306.h>
#include <IonTrail.h>
#include "iontrail_board.h"
#include "climate_reading.h"

IonTrailDevice ionTrail;
Adafruit_SHT4x climate;
Adafruit_SSD1306 display(128, 64, &Wire, -1);
bool counterReady = false, climateReady = false, displayReady = false;
bool resetHeld = false, resetDone = false;
uint32_t resetSince = 0, lastUi = 0;
uint32_t lastDisplayProbe = 0;
constexpr uint32_t kDisplayProbePeriodMs = 2000;
ClimateReading environment;

bool i2cPresent(uint8_t address) {
  Wire.beginTransmission(address);
  return Wire.endTransmission() == 0;
}

bool startClimate() {
  if (!i2cPresent(0x44) || !climate.begin(&Wire)) return false;
  climate.setPrecision(SHT4X_MED_PRECISION);
  climate.setHeater(SHT4X_NO_HEATER);
  return true;
}

void serviceDisplay(uint32_t now, bool force = false) {
  if (!force && uint32_t(now - lastDisplayProbe) < kDisplayProbePeriodMs) return;
  lastDisplayProbe = now; // One attempt per period; never catch up in a burst.
  const bool wasReady = displayReady;
  if (!i2cPresent(IonTrailBoard::kDisplayAddress)) displayReady = false;
  else if (!displayReady) {
    // The pinned driver reuses its framebuffer. Do not restart shared Wire or
    // repeatedly initialize an already-available display. ACK is not pixel feedback.
    displayReady = display.begin(SSD1306_SWITCHCAPVCC, IonTrailBoard::kDisplayAddress,
                                 false, false) && i2cPresent(IonTrailBoard::kDisplayAddress);
  }
  if (!force && wasReady != displayReady)
    Serial.println(displayReady ? "# oled available; address ACK, pixels unverified" :
                                  "# oled unavailable; serial counting continues if counter ready");
}

void setup() {
  Serial.begin(115200);
  pinMode(IonTrailBoard::kButtonPrimaryPin, INPUT_PULLUP);
  pinMode(IonTrailBoard::kStatusLedPin, OUTPUT);
  Wire.begin(IonTrailBoard::kI2cSdaPin, IonTrailBoard::kI2cSclPin);
  Wire.setClock(100000); Wire.setTimeOut(50);
  climateReady = startClimate();
  serviceDisplay(millis(), true);
  IonTrailConfig config;
  config.gmPulsePin = IonTrailBoard::kGmPulsePin;
  config.sampleWindowMs = 10000; config.deadTimeMicros = 0;
  counterReady = ionTrail.begin(config);
  Serial.printf("# IonTrail EVT-A counter=%d sht40=%d oled=%d\n", counterReady, climateReady, displayReady);
  Serial.println("# CPM only; not calibrated dose. Zero counts cannot prove detector health.");
  Serial.println("uptime_ms,window_ms,window_counts,cpm,total_counts,temperature_c,humidity_percent,sensor_ok,counts_valid");
}

void loop() {
  if (counterReady) ionTrail.update();
  uint32_t now = millis();
  if (counterReady && digitalRead(IonTrailBoard::kButtonPrimaryPin) == LOW) {
    if (!resetHeld) { resetHeld = true; resetSince = now; }
    if (!resetDone && now - resetSince >= 2000) {
      ionTrail.resetTotals(); resetDone = true;
      Serial.println("# totals reset; wait one full 10-second window");
    }
  } else { resetHeld = false; resetDone = false; }
  if (counterReady && ionTrail.hasFreshReading()) {
    // Retry boot-time absence once per completed count window. Once initialized,
    // use getEvent for transient recovery; do not repeatedly reinitialize a live driver.
    if (!climateReady) climateReady = startClimate();
    bool readOk = false;
    sensors_event_t h{}, t{};
    if (climateReady) {
      readOk = climate.getEvent(&h, &t);
    }
    const uint32_t climateAt = millis();
    environment.update(readOk, t.temperature, h.relative_humidity, climateAt);
    const bool sensorOk = environment.valid(climateAt);
    Serial.printf("%lu,%lu,%lu,%.2f,%lu,%.2f,%.2f,%d,%d\n",
                  static_cast<unsigned long>(now),
                  static_cast<unsigned long>(ionTrail.lastWindowMs()),
                  static_cast<unsigned long>(ionTrail.lastWindowCounts()), ionTrail.cpm(),
                  static_cast<unsigned long>(ionTrail.totalCounts()),
                  environment.temperature(climateAt), environment.humidity(climateAt),
                  sensorOk, !ionTrail.overflowed());
  }
  now = millis(); // Climate I/O takes time; never compare a sample to an older clock.
  serviceDisplay(now);
  now = millis(); // Display initialization/probes also use synchronous I2C.
  if (now - lastUi >= 500) {
    lastUi = now;
    digitalWrite(IonTrailBoard::kStatusLedPin, !digitalRead(IonTrailBoard::kStatusLedPin));
    if (displayReady) {
      display.clearDisplay(); display.setTextColor(SSD1306_WHITE);
      display.setTextSize(1); display.setCursor(0, 0); display.println("IONTRAIL EVT-A");
      display.setTextSize(2);
      if (!counterReady) display.print("INIT FAIL");
      else if (ionTrail.overflowed()) display.print("FAULT");
      else if (ionTrail.lastWindowMs()) display.print(ionTrail.cpm(), 1);
      else display.print("WAIT");
      display.setTextSize(1); display.println(counterReady ? " CPM" : "");
      display.printf("Total %lu\n", static_cast<unsigned long>(ionTrail.totalCounts()));
      if (environment.valid(now))
        display.printf("%.1f C / %.1f %%RH\n", environment.temperature(now), environment.humidity(now));
      else display.println("Climate unavailable");
      display.println("Not a safety meter"); display.display();
    }
  }
  delay(1);
}

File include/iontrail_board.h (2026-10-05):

#pragma once

// Provisional EVT pin map for a common ESP32-C3 SuperMini layout.
// Verify the schematic and silk screen of the exact purchased board.
// Do not reuse native USB or boot-strapping pins without checking startup behaviour.

namespace IonTrailBoard {
constexpr int kGmPulsePin = 3;
constexpr int kI2cSdaPin = 4;
constexpr int kI2cSclPin = 5;
constexpr int kBuzzerPin = 6;
constexpr int kStatusLedPin = 7;
constexpr int kButtonPrimaryPin = 0;
constexpr int kButtonBackPin = 1;
constexpr int kButtonNextPin = 10;
// EVT-A has no internal battery; GPIO2 is a boot strap and left unused.
constexpr int kBatteryAdcPin = -1;
constexpr int kDisplayAddress = 0x3C;
}  // namespace IonTrailBoard

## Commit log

2026-10-05 Build IonTrail bench draft with sensor firmware, wiring and CAD
    [fixture-plate.step, fixture-plate.stl, layout-draft.step]
2026-10-05 Draft secondary bench enclosure and test low-voltage power budget
    [bench-lid-draft.step, bench-lid-draft.stl, bench-tray-draft.step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]
2026-10-05 Track climate reading validity and retry boot-time sensor absence
2026-10-05 Add source-checked enclosure visual handoff
2026-10-05 fix: retry missing OLED with bounded connection checks
    [main.cpp, test_app.cpp]
